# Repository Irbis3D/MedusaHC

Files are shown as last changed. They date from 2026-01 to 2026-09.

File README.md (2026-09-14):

# MedusaHC V0.2 (Beta)

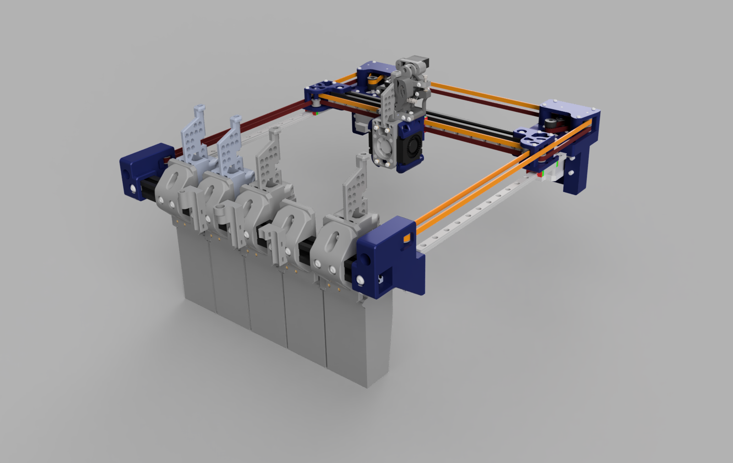
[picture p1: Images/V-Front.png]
MedusaHC V-Front


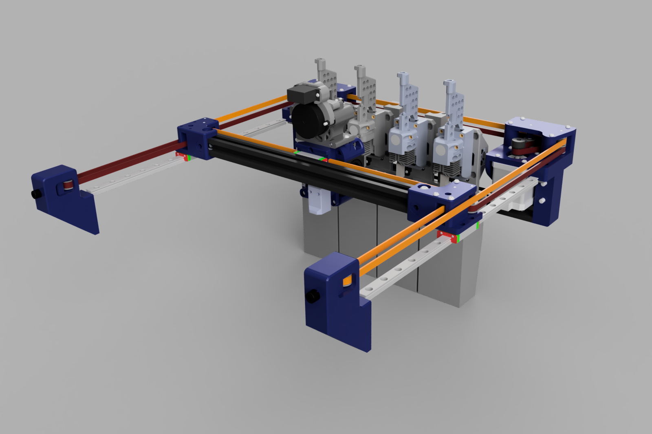
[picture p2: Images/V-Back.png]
MedusaHC V-Back


MedusaHC is an open-source toolchanger (hotend-changer) project.
This is a beta version of the project. It is not finished yet, and there may be bugs during operation. The project will be updated gradually.

> [!IMPORTANT]
> **[Installation, update, removal, and manual setup instructions](INSTALLATION.md)**
>
> **If, for any reason, you are still using the macro-based version, it is available in the [legacy-macros branch](https://github.com/Irbis3D/MedusaHC/tree/legacy-macros). However, I strongly recommend migrating to the new Python-based version while the transition is still straightforward.**

This project is licensed under GNU GPLv3.
You're free to use, modify, and share it — just keep the copyright/license notices intact, provide the source code, release derivatives under GPLv3 too, and note what you changed.

For the exact terms, see the LICENSE file.

## Support the project

If you have the ability and desire to support the project, you can do it in several ways:

https://irbis3d.xyz/

- Patreon — monthly support: https://patreon.com/Irbis3D
- Ko-fi / Buy Me a Coffee — one-time donations: https://buymeacoffee.com/Irbis3D
- YouTube Super Thanks — under any video: https://youtube.com/@Irbis3D

Your support helps me create more content, upgrade gear, and keep experimenting with cool ideas.

Also, by buying parts using my links, you help as well.

## Software options

> [!IMPORTANT]
> The `main` branch now uses the Python-based tool-change controller. It has
> completed extended testing on the development printer, has proven reliable,
> and is the strongly recommended implementation for new and existing
> installations. Current optional MedusaHC modules are developed against it.

The controller keeps the familiar MedusaHC commands and configuration
structure while moving pickup, parking, feeder, priming, cleaning, and sensor
verification into the Klipper Python module `medusahc.py`. This avoids the
chained execution and unnecessary fixed waits of the original macro controller.

The final working macro-based implementation is preserved in the frozen
[`legacy-macros`](https://github.com/Irbis3D/MedusaHC/tree/legacy-macros)
branch. It retains the old klipper-toolchanger calibration workflow and is
provided for compatibility and rollback, but new functionality is not planned
for that branch. Migration to the Python controller is strongly recommended.

The optional [MedusaHC Control](https://github.com/Irbis3D/MedusaHC-Control)
panel is installed independently. Its current transitional release supports
the Python controller and the preserved legacy macro names.

Optional features are kept in separate projects so they can be installed and
updated independently:

- [MedusaHC-Calibrate](https://github.com/Irbis3D/MedusaHC-Calibrate) — automatic
  tool-offset calibration using a contact sensor, native Eddy Tap, or Eddy Tap
  together with a stationary Eddy Coil and EddySeek;
- [MedusaHC-Mainsail](https://github.com/Irbis3D/MedusaHC-Mainsail) — experimental
  Mainsail integration for the MedusaHC Control panel.

The base MedusaHC configuration does not require either optional module.

## Credits

This project uses some work and ideas from the Dragonburner project by chirpy2605:
https://github.com/chirpy2605/voron/tree/main/V0/Dragon_Burner

As well as from Sherpa_mini-Extruder by Annex-Engineering
https://github.com/Annex-Engineering/Sherpa_Mini-Extruder

The alternative V-Front mounts with a profile opening were contributed by **GN500**. GN500 has also published an MGN12H version on Printables.

## Current status and compatibility

Right now, MedusaHC is an add-on for my Duender project:
https://www.printables.com/model/1798903-duender-project-ender-3-to-corexy-conversion
https://github.com/Irbis3D/Duender

V0.2 supports two basic dock layouts:

- **V-Front** — the hotend bases are installed in front of the print area. This layout can accommodate more tools and may be more convenient when adapting MedusaHC to other CoreXY printers, including Voron-style machines.
- **V-Back** — the hotend bases are installed behind the print area, closer to the XY motors. The shorter effective belt path between the drive and the dock area reduces the influence of belt elasticity during tool changes and can improve docking repeatability. It also keeps the front of the printer unobstructed and the print area easy to see.

The supplied STEP assembly is a visual and mechanical reference. It demonstrates that up to **5 tools** can fit in the V-Front layout and shows a **4-tool** V-Back arrangement. The supplied configuration and OrcaSlicer profile are intentionally set up for **4 tools**.

The project can potentially be adapted for other classic CoreXY printers and, with suitable mounting changes, for CoreXY machines with a flying gantry. Available space, axis travel, dock coordinates, parking positions, wiring, and controller capacity must be checked for every printer.

The point of the project is that, unlike classic toolchangers, MedusaHC swaps only the hotend as a tool (with heater, thermistor, and fan). I am not the first who did this and I will not be the last. This topic is actively discussed and developed on my
Discord server - https://discord.gg/ae44FHv786

## What is new in V0.2

- V-Front and V-Back dock layouts use the same Python tool-change controller.
- `variable_tools_direction` automatically reverses layout-dependent pickup, drop, cleaning, and priming movements.
- The supplied configuration uses four tools numbered normally from `T0` to `T3`.
- The base, nozzle-cleaning, PTFE-cleaning, priming, and wire-management parts have been updated.
- Native Klipper Eddy tap replaces Eddy-ng for Z probing.
- Automatic tool-offset calibration is available separately through
  MedusaHC-Calibrate and does not require klipper-toolchanger.
- Updated OrcaSlicer projects, a 4-tool printer preset, and post-processing scripts are included.
- Camera-assisted tool calibration is not currently supported. A new native or
  adapted camera module may be developed later.

See [CHANGELOG.md](CHANGELOG.md) for the complete V0.2 release notes.

## Documentation and audience

For a general understanding, I recommend watching the first video about this project on my YouTube channel. You will not find all the information there, but you can get a general idea of how it works.

MedusaHC video (https://www.youtube.com/watch?v=hpV5Z1TnGdY)

Recently a video about the hardware part of MedusaHC was released on the channel. In the next video I will explain the software side — configuration, macros, and how everything is set up.

MedusaHC Part 2 — Hardware Explained (https://www.youtube.com/watch?v=F2OpeA6CTm0)

But the main thing is that, thanks to the huge effort of **TallothEndill**, a detailed text manual is already in progress and largely covers the project. It is not fully finished yet, but it is already very useful as a reference:

[MedusaHC manual (work in progress)](https://drive.google.com/file/d/1KkSGdeQZzl4gnCMKlBloHfCNIlD4JwAP/view)

## Parts, BOM, and files

Link to BOM

https://docs.google.com/spreadsheets/d/1xkOzb10DBJzalW4n1tYroh-m_ZFsTQipC1BpUh5ZMWY/edit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

For this project you need to buy quite a lot of parts. I tried not to use expensive and rare components. You can find the list at the link above. This file will be updated as the project updates.

The full STEP file contains both V-Front and V-Back reference assemblies. It is primarily intended to show the construction, available space, and the relationship between the parts. It is not a promise that the example tool count matches the supplied 4-tool configuration. The file was created in Fusion 360; FreeCAD may have problems opening it because of STEP compatibility differences.

Printable STL files are organized by subsystem. The layout-specific mounting parts are separated into `V-Front Mounts` and `V-Back Mounts` folders. Common base, feeder, hotend, and toolhead parts are stored in their own folders.

The OrcaSlicer 3MF projects and the 4-tool printer preset are located in the `Slicer` folder. They show the printer configuration and a multicolor test project. Post-processing paths are computer-specific and must be configured by the user.

To understand how the system is assembled, use the STEP file together with the STL folder descriptions. I printed the functional parts in ABS with 98% infill.

### Duender XY mounting compatibility

The layout-specific mounts supplied in this V0.2 package are designed for a **Duender with MGN9H rails on the XY axes**.

An MGN12H installation requires the MedusaHC mounting system to be raised slightly to compensate for the different rail and carriage geometry. The required correction depends on the selected Duender parts and must be checked during assembly.

#### V-Front installation

There are two mounting options for a front installation:

1. Keep the standard Duender front XY mounts and glue the included `Base_Profile_Mount_L.stl` and `Base_Profile_Mount_R.stl` adapters to them. The adapters are located in `STLs/V-Front Mounts`.
2. Replace the standard front mounts with the V-Front mounts contributed by GN500. These mounts include an opening for the front profile. The MGN9H versions are included in this package; an MGN12H version is available from GN500 on Printables.

No other Duender kinematic changes are required for the V-Front installation. The X rail and belt path remain in their normal orientation.

#### V-Back installation

For a rear installation, the standard Duender front mounts remain installed. The MedusaHC docks are attached to the rear profile using the new V-Back mounting parts.

Because all tools are behind the X axis, the complete X axis must be turned toward the rear:

- install the new reversed left and right X-axis mounts;
- move the X linear rail to the opposite side of the profile;
- route the belts behind the X profile;
- check the complete belt path and all moving clearances before homing.

At the toolhead belt clamp, several belt teeth must currently be removed from the clamped section so the carriage can seat fully. A small drop of cyanoacrylate adhesive can be used to reduce the risk of belt slippage. This is a temporary assembly solution and may be redesigned later.

Depending on the printer geometry and the required rear clearance, the complete Z axis together with the bed may also need to be shifted forward.

## Important notes

All parts must be printed with good enough quality so that parts do not get stuck inside each other. Some contact surfaces may need a bit of sanding to make them smooth.

When installing magnets (I glued them, and all magnet holes have access from the back for removing magnets), be careful and do not mix up the polarity.

The M3 pins that act as hotend guide pins must be pressed into the plastic as straight as possible. I hammered them in, but it is better to do it carefully using a vise. The two lower M3 30mm pins are mandatory. The upper M3 20mm pins are optional, if the hotend does not hold firmly enough.

On the hotend, the matching holes for the pins must be prepared. Personally, I used M3 inserts for this, and I drilled them first with a 3mm bit (they are usually about 2.9mm), and then with a 3.2mm bit (my bits are closer to 3.1mm). Even though the size looks odd, these drill bits are quite common.

Before drilling the actual part, I recommend testing on some test piece to make sure the hole is not too large. The pins must slide in freely, but must not be loose.

Maybe later it will be possible to use brass bushings of the correct diameter, but they take more space and may not fit.

The pressure lever spring for the feeder from the standard Sherpa Mini kit does not fit. I just found a suitable spring in my spare parts. When a spring with known dimensions is selected, I will add this information to the BOM.

The spring for the feeder opener lever is just a regular spring from a ballpoint pen.

Other than that, you just need to assemble everything carefully so nothing is loose and nothing binds. As I said earlier, I will explain more nuances in the video.

## Electronics

For this project, I use the **BTT Manta M8P** board. For a 4-hotend configuration, it can be considered the most optimal option. It has enough ports for absolutely everything, including 4 hotend heaters and even a dedicated Servo port (which is sufficient without a DC-DC converter). My configuration files are set up specifically for this board with a **CB2** module.
https://s.click.aliexpress.com/e/_oktZaKt

Roughly the same capabilities are provided by boards like **BTT Octopus Pro**, **Kraken**, and other “large” boards, with the main difference being that the HOST is located separately.
https://s.click.aliexpress.com/e/_c2wuASWJ
https://s.click.aliexpress.com/e/_c3kPDyx1

When using other boards, it is possible to connect additional boards to a single host.

### Ports required per hotend (on the controller board)

For each hotend, the board must have the following ports:

- heater port (MOSFET-controlled; can be used either hotend heaters or the bed)
- thermistor port
- fan port (either PWM-controlled or a constant 24V port)
- endstop port for the endstop located on the base of that hotend

### Ports required for the toolhead

- one extruder motor port
- part cooling fan port(s)
- toolhead endstop port
- port for the auto-calibration sensor (I use **BTT Eddy** connected via CAN)
- servo port — if the board does not have a dedicated servo port capable of supplying stable 5V under load, it is recommended to power the servo via a **24V→5V DC-DC converter** from the main power supply

### Power considerations

Additional hotends require additional power from the PSU.

From experience, a standard **350W** power supply is reliably sufficient for **2 hotends**.
For **3 hotends**, it can be enough with a high-quality PSU.
For **4 hotends**, it is definitely not enough.

In my setup with the **Manta M8P**, I use one **350W** power supply for the heated bed, and another **350W** power supply for everything else.

## Configuration setup

The main printer parameters, as before, are located in the `printer.cfg` file.
In general, the configuration is no different from a standard Duender config.

The exception is that the extruder configuration block has been moved into the MedusaHC configuration file. More on this below.

### Additional modules

Personally, I use **klipper-tmc-autotune** for tuning motor drivers.
(This is optional.)

### Display and sensors

In my opinion, the optimal screen is **BTT HDMI5**.

https://s.click.aliexpress.com/e/_c4odBUeJ

I use **BTT Eddy** connected through CAN. V0.2 no longer uses Eddy-ng or a modified `probe_eddy_ng.py` file. Eddy tap probing is handled by current Klipper functionality.

Native Eddy Tap can be used by the optional MedusaHC-Calibrate module to
measure the Z relationship between tools. Full X/Y/Z calibration can use a
SexBall-style contact sensor or combine Eddy Tap for Z with a stationary Eddy
Coil and EddySeek for XY.

## Arcs support

The `[gcode_arcs]` block and the **Arc fitting** setting in the slicer allow the slicer to use **G2** and **G3** commands to print arcs instead of short straight segments.

On weak HOST systems, problems were observed with this feature. In such cases, it should either be disabled or the resolution should be set higher than **0.1**.

## System configuration files modified for this setup

### sensorless.cfg

This file has been modified quite heavily to make sensorless homing safer and to improve repeatability without physical XY endstops.

The safe parking and homing side depends on the dock layout:

- with **V-Front**, park away from the docks, toward the rear of the printer;
- with **V-Back**, park away from the docks, toward the front of the printer.

The exact coordinates depend on the printer. Check the homing sequence and every parking move before testing at normal speed. Parking positions used by `END_PRINT`, `PAUSE`, `RESUME`, `CANCEL_PRINT`, calibration macros, and service macros must also be adjusted for the selected layout.

The supplied Duender 4-tool configuration uses front docks and rear parking.

### Line_Purge_examples.cfg

Modified so that the purge line is printed not along the X axis, but on the left side of the bed along the Y axis.

In my setup, **Adaptive** is disabled, so the line is always printed in the same place. It can be enabled if desired, in which case the line will be printed closer to the model.
(Optional.)

### klipperScreen.conf

KlipperScreen support is optional. A custom menu can be created for the main MedusaHC macros, but `KlipperScreen.conf` is not included in this V0.2 folder.

### Camera calibration

Camera-assisted tool calibration is not currently supported. The previous
experimental example was not compatible with the current configuration and
has been removed. A new native implementation or an integration with another
project may be added later.

### macros_examples.cfg

The `START_PRINT`, `END_PRINT`, `PAUSE`, and `RESUME` macros were heavily modified.

The start macro receives from the slicer the required temperatures for the hotends that will be used during the print and heats them up. At the moment, it does not take into account whether a hotend will be used soon or should wait its turn. I am not happy with this behavior yet, but I have not found a good solution so far.

The pause and resume macros are also heavily adapted for this system. The idea is that during tool changes, the printer remembers which tool it is trying to pick up. In case of a failure, the printer pauses and gives time to fix the issue.

It is enough to manually adjust the hotends so that they are in one of the “correct states” and then press resume. Regardless of what was done manually, the printer will automatically check which hotend it planned to take before the pause, park the X and Y axes (this is necessary if the motors skipped steps), and then ensure that the print continues with the correct hotend.

This procedure still has some shortcomings. A visible defect may remain on the model at that spot. Additionally, when parking with sensorless homing, the zero point may shift slightly, which can appear on the model as a small layer shift. In most cases, this shift is very small.

---

## MedusaHC configuration

### Semi-manual Core installation

The Core installer copies the Python controller and `pin_watch.py`, then creates
a separate editable example configuration under
`~/printer_data/config/MedusaHC/`. It does not edit `printer.cfg`, restart
Klipper, or overwrite an existing configuration directory.

```bash
bash -c "$(curl -fsSL https://raw.githubusercontent.com/Irbis3D/MedusaHC/main/install-online.sh)"
```

The supplied example targets a four-tool V-Front Duender with a BTT Manta M8P
V2.0. Its `MHC_config.cfg` contains a complete `[extruder]` definition, so
review and remove conflicting sections from the existing printer configuration
before manually adding:

```ini
[include MedusaHC/MHC_config.cfg]
```

See **[INSTALLATION.md](INSTALLATION.md)** for update, status, safe removal,
complete removal, path overrides, exact installer behavior, and manual
installation instructions. Core configuration migration and automatic printer
setup are intentionally not implemented yet.

The main files responsible for MedusaHC operation are:

- `MHC_config` — configuration of all hardware related to MHC
- `MHC_variables` — variables for configuring various coordinates, speeds, and similar parameters
- `MHC_macros` — the main file containing all macros responsible for MHC functionality

And the `pin_watch.py` script — in the current version, a dedicated script is used to monitor sensor states. It listens to the sensors in real time and updates variable states accordingly. Based on this data, MHC determines what is installed where and checks for errors.

The file must be uploaded via FTP to the folder:

```

/home/biqu/klipper/klippy/extras

```

(` /home/pi/klipper/klippy/extras ` for Raspberry Pi users)

The script was integrated recently and has not been tested on different systems yet. If problems appear, I will make an additional version that works purely on macros, with manual state updates via a macro. (Feedback is required.)

All (or at least almost all) macros are designed to be universal and work with any number of hotends. The number of hotends is defined in the configuration and variables. My current config is for **4 hotends** (higher counts have not been tested yet).

## MHC setup

### MHC_config file

#### [pin_watch io] block

This block configures the `pin_watch` script.

- `sync_toolchanger: 0` — optional compatibility synchronization with
  klipper-toolchanger. It is disabled by default and is not required by
  MedusaHC or MedusaHC-Calibrate. Enable it only after installing and minimally
  configuring klipper-toolchanger separately.
- `sync_mainsail_tools: 1` — highlights the active tool button in the Mainsail/Fluidd tools panel. When a tool is successfully picked up, the corresponding `T<N>` button gets `variable_active = 1`, others get `0`.
- `sync_mainsail_sensors: 1` — turns each tool's button into a state indicator lamp via `variable_color`. The active tool is shown in blue, parked tools (endstop pressed) in green, missing tools (endstop released) in red. The lamp is updated immediately from pin edges, so anomalies are visible in real time.
- `color_active`, `color_pressed`, `color_released` — hex colors (without `#`) used by the indicator lamp. Defaults: blue / green / red.
- `verbose` — enables additional console output with detailed pin state information.
- `pin_e` — microswitch pin located on the toolhead.
- `pin_t0`, `pin_t1`, etc. — microswitch pins on the bases of the corresponding hotends.

Each sync feature is independent. Enable only the integrations you actually
use.

#### [duplicate_pin_override]

Since a single extruder motor is used for all tools, this block must specify the **step**, **dir**, and **enable** pins for that motor. This allows all extruders to use the same pins without causing configuration errors.

#### [extruder], [extruder1], etc.

Nothing special here. All extruders share the same **step**, **dir**, and **enable** pins. The rest is standard extruder configuration.
A corresponding `extruder` block must be created for each hotend.

#### [gcode_macro T0], [gcode_macro T1], etc.

Mandatory macros that “create” additional tools in the system.
The number of these macros must match the number of hotends.

Each `T<N>` macro must declare two variables: `variable_active: 0` and `variable_color: ""`.
These are required by Mainsail/Fluidd to render the tools panel and to receive runtime updates from `pin_watch` when `sync_mainsail_tools` or `sync_mainsail_sensors` is enabled.

#### [servo my_servo]

The last mandatory block. This defines the servo used to help open the feeder.

After that come optional parameters:

- fan configuration (if you are using controllable fan ports)
- additional heater parameters

It is recommended to change heater-related parameters only if there are heating problems, and only as a last resort, preferably temporarily.

---

### MHC_variables file

#### [save_variables]

This block defines the file where tool offsets are stored so they can be restored after a restart.
(It is required when using auto-calibration.)

#### [gcode_macro _TOOL_CFG]

This macro contains the main coordinates and distances used in the system, as well as the speeds and accelerations for the tool change procedure.

- `variable_tools_direction` — selects the dock orientation:
  - `1` for **V-Front**;
  - `-1` for **V-Back**.

  This value automatically reverses the required pickup, drop, cleaning, and priming movements. Do not manually invert the individual movements in `MHC_macros.cfg`.

- `variable_x_t0`, `variable_x_t1`, etc. — the **X coordinate** where each hotend is mounted on its base.
  Enter the real printer coordinates and keep the tools numbered normally from `T0` upward. The supplied Duender configuration uses **65 mm** spacing. The minimum safe spacing depends on the printed parts, hotends, wiring, and available travel.

- `variable_y_safe` — the **Y coordinate** where the extruder with an inserted hotend can freely move left and right without hitting other hotends on their bases.
  For V-Front this is normally in front of the bed; for V-Back it is behind the bed. Depending on the frame and profile lengths, the dock area may reduce usable Y travel.

- `variable_y_latch` — the **Y coordinate** where the toolhead fully engages with the hotend.
  This must be set very precisely so that the toolhead presses firmly against the hotend, but without causing the motors to skip steps.

- `variable_x_shift` — the distance the hotend needs to move along the X axis from `variable_x_t` in order to remove it from the base keyhole.

- `variable_fast_accel`
- `variable_fast_speed` — speeds and accelerations for tool changes. During the change process, there are slowdowns that are calculated as proportions of these parameters.

- `variable_y_prime` — the **Y coordinate** where it is safe to prime filament into the bin.
- `variable_y_brush` — the **Y coordinate** of the approximate center of the nozzle cleaning brush.
- `variable_x_prime_shift` — the **X distance** from `variable_x_t` to the priming point.

The user only needs to select `variable_tools_direction` and enter the correct coordinates. The MedusaHC macros derive the movement direction from that setting. Parking coordinates outside the MedusaHC tool-change macros are printer-specific and must still be checked separately.

- `variable_e_open`
- `variable_e_close` — the distance and direction (in mm of filament) the extruder motor rotates to open and close the feeder latch.
  Sign sets direction: by default open is negative, close is positive. Flip the sign if your extruder is wired or mounted the other way around.

- `variable_e_cur_high_mult` — multiplier applied to the extruder's base TMC `run_current` to get the boosted current used during feeder **OPEN**.
  The boost is needed so the motor has enough torque to break the mechanical lock without skipping steps. Typical range: **1.3 – 1.8**.
  Base and boosted currents are cached at initialization. Save changes to the
  multiplier or `run_current` in the configuration and restart Klipper while idle.

#### [gcode_macro _GLOBAL_STATE]

- `variable_max_tool: 4` — required by the macros to operate with the specified number of hotends.

After this, there are parameters that are used internally by the macros.
They should **not** be changed.

#### [gcode_macro _TOOL_STATE_0], [gcode_macro _TOOL_STATE_1] and so on

Each hotend must have its own `TOOL_STATE` macro (`_TOOL_STATE_0`, `_TOOL_STATE_1`, and so on), where all parameters for that specific hotend are defined.

- `variable_prime_amount` — the amount of filament (in mm) extruded during priming.
  A small value (**7–8 mm**) is suitable when printing with a draft/wipe tower.
  A larger value (**14–16 mm**) can be used for printing without a tower.

- `variable_prime_speed` — priming speed.

- `variable_prime_retract`, `variable_prime_retract_speed` — length and speed of the retract after priming.

- `variable_clean_move` — `1` to perform the complete PTFE and brush-cleaning sequence after priming; `0` to skip all cleaning movements and move directly to `y_safe`.

- `variable_x_clean_move`

- `variable_y_clean_move`

- `variable_clean_move_speed` — brush crossing speed in mm/s for this tool, used both by CLEAN and by cleaning after pickup. Read from `_TOOL_STATE_n` on each operation; changes apply to the next cleaning cycle.

Pickup moves to `y_prime` at the X position set by `x_prime_shift` before
extrusion. All priming and the prime retract finish there. The next move is
to `y_brush`, before any cleaning X stroke. The entire slow/fast PTFE path
then runs relative to `y_brush`; the crossing starts 2 mm toward the dock from this
reference, preserving the original mirrored geometry. Both Y values default
to -45 mm. The PTFE passes retain `ptfe_clean_slow_speed`.

- `variable_clean_retract`

- `variable_clean_retract_speed` — additional retract after cleaning.

- `variable_first_prime_enabled` — `1` to enable first-use priming for this tool, `0` to disable it.

- `variable_first_prime_flag: 1` — internal runtime state managed by the macros. Do not change it manually.

- `variable_first_prime_amount` — the amount of filament (in mm) extruded during the first use of the hotend in a print.
  This value is usually larger than the regular priming amount.

- `variable_first_prime_speed` — speed of the first-use priming.

## Notes

Keep in mind that the lengths of these two retracts are linked to the slicer parameter **“Retraction when switching material”**.
If the priming retract and the cleaning retract are **1 mm** each, then **“Retraction when switching material”** must be set to **2 mm**.

In some situations, with certain filaments and when printing without a draft tower, these parameters require additional calibration.

## Main macros file

And finally, the most important file. Nothing needs to be configured here (hopefully it will stay that way).
I will not describe the system operation in full detail here. I will explain it a bit more in the video.
Below is a short overview, just to understand the main algorithms.

---

### Python initialization

The Python controller initializes after Klipper becomes ready; there is no
`INIT_SENSOR_STATE` macro on `main`.
It is responsible for:

- assigning variables that depend on printer parameters
- initial tool assignment
- applying tool offset values from the `saved_vars` file to the variables in `[gcode_macro _TOOL_OFFSET]`

---

### Feeder control macros: OPEN, CLOSE and sub-macros

These macros control the feeder.

The Python controller ignores OPEN when its stored feeder state is already open.

There are no dedicated sensors to track the feeder state, so the state is stored in a variable. The printer uses this variable to determine whether the feeder is open or closed.

Since closing the feeder is relatively safe, it is forced on printer startup. From that moment on, the printer knows the feeder state and will not try to open it incorrectly.

The old macro controller documented an OPEN/CLOSE workaround after motor
disable. That is not part of the current slicer start sequence, which calls
CLOSE. The Python controller tracks feeder state internally.

---

### Python tool-change controller

The physical pickup, drop, feeder, cleaning, priming, offset, and verification
logic is implemented by `klippy/extras/medusahc.py`. The short public macros retain
the familiar Mainsail and slicer interface without exposing internal helper
commands.

The **main command responsible for tool changes is `SET`**. It is also called
by the `T` macros.

When `SET` is called with a tool parameter (`SET T=0`, `SET T=1`, etc.), the printer checks what is currently installed, based on data from the `pin_watch` script object.

- If no hotend is installed, the printer will pick up the requested hotend.
- If a different hotend is installed, the printer will first drop it, then pick up the requested one.
- If the requested hotend is already installed, the printer will simply apply the offsets for the selected tool and finish.

All of this happens automatically, without the need to manually specify anything.

Thanks to the `pin_watch` script, the printer always knows its state, even if you manually remove or install hotends.

---

### Dropping a tool and error handling

Use the public `DROP_TOOL` command to park the currently installed hotend.
The included `_DROP` macro calls `MHC_DROP` for internal users such as
MedusaHC-Calibrate; it does not add a Mainsail button.

---

All pickup and drop macros include checks.

If after dropping or picking up a hotend the script detects that the sensor state does not match the expected one (for example, the drop failed, pickup failed, or some other hotend fell off its base), the printer will pause and enter an error state.

After fixing the problem and resuming, the printer will pick up the planned tool and continue printing.

The current Python controller distinguishes an undetermined live sensor state
from a failed SET/DROP operation. Interfaces can use `medusahc.sensor_error`
and `medusahc.last_error`; see the [sensor status guide](docs/sensor-status.md).
Recovery after a failed change, and manual PAUSE/RESUME behavior, require the
active printer macros to call `MHC_RESUME`. See the
[PAUSE/RESUME migration guide](docs/recovery.md) before updating a printer.

The frozen macro implementation and its original chained helper macros remain
available in the `legacy-macros` branch.

---

## Orca Slicer configuration

All slicer settings can be viewed by opening `Slicer/4rcaCube_orca_project.3mf` as a project. A separate 4-tool printer preset is provided in `Slicer/Printer presets.zip`.

All MHC-specific parameters are located in the printer settings.

### Machine G-code tab

The following sections are modified:

- Start G-code

```gcode
CLEAR_PAUSE
_PRIME_FLAGS_SET
M104 T0 S150
M190 S[bed_temperature_initial_layer_single]
G28
Z_TILT_ADJUST
CLOSE
START_PRINT INITIAL_TOOL=[initial_tool] INITIAL_TEMP={first_layer_temperature[initial_tool]} EXTRUDER_TEMP={is_extruder_used[0] ? idle_temperature[0] : 0} EXTRUDER1_TEMP={is_extruder_used[1] ? idle_temperature[1] : 0} EXTRUDER2_TEMP={is_extruder_used[2] ? idle_temperature[2] : 0} EXTRUDER3_TEMP={is_extruder_used[3] ? idle_temperature[3] : 0} BED_TEMP=[bed_temperature_initial_layer_single]
PRIME_FLAGS_CLEAR
T{current_extruder}
CLEAN
LINE_PURGE
G92 E0
```

- End G-code

```gcode
END_PRINT
```

- Change filament G-code

```gcode
T{next_extruder}
```

- The **Layer change G-code** also includes a modification that assigns a layer variable. It is not used at the moment, but may be useful in the future.
```gcode
;AFTER_LAYER_CHANGE
_LAYER_SET L={layer_num}
;[layer_z]
```

### Multimaterial tab

You must specify the number of extruders. After that, separate tabs with settings for each hotend will appear.

All print parameters related to multimaterial printing are also located in the **Multimaterial** tab.

---

## G-code post-processing script

In addition, to optimize the workflow, I use a G-code post-processing script called `SET_FINISH.py`.

This script slightly changes the order of movements when transitioning back to printing after a tool change.
It also replaces some temperature commands that include waiting with non-waiting commands.

This is done so that, when **Ooze prevention** is enabled, the printer does not wait for temperature stabilization after every tool change.

Be careful with **Ooze prevention** settings. The heating time must always be sufficient for the hotend to reach the target temperature.

To use this script, **Python must be installed on the computer**.
You must specify the path to Python and to the script itself in the **Others** tab, in the **Post-processing Scripts** section.

The path stored in a 3MF project is computer-specific. Replace both paths with the actual Python executable and the copy of the script on your computer. A typical command has this form:

```

"C:\path\to\python.exe" "C:\path\to\SET_FINISH.py" 12

```

`SET_FINISH_Snapmaker_Orca.py` is also included for the alternative workflow used with Snapmaker Orca. See the `Scripts` folder README before selecting a post-processing script.

## Tool offset calibration

Offsets work relative to the first tool.
That means all offsets for **T0** are equal to `0`, and all other tools are calculated relative to **T0**.

Keep in mind that this system uses **G-code offsets**.
That is, how much the entire coordinate system needs to be shifted so that the hotend ends up in the same position as **T0**.

Do not confuse this with *tool offset*, where the value indicates how much the hotend itself is shifted from the desired point.

As a result, **tool offset has the opposite sign of the G-code offset**.

---

### Manual tool offset calibration

Saved offsets override the initial `_TOOL_OFFSET` values in `MHC_variables.cfg`
at startup. Do not disable initialization for manual calibration. Save your
measured G-code offsets with `SAVE_VARIABLE`, using keys such as
`t1_gcode_x_offset`, `t1_gcode_y_offset`, and `t1_gcode_z_offset`.
For example: `SAVE_VARIABLE VARIABLE=t1_gcode_x_offset VALUE=0.12`.
Restart Klipper while idle to load these values into `_TOOL_OFFSET`.

---

### Z offset calibration

Z calibration is done manually, via the web interface or the printer menu.

Lower each hotend to the bed and calculate the offset relative to the first hotend.

---

### XY offset calibration

For this, you need to print special calibration models.
I used this one:

https://www.printables.com/model/129617-offset-xy-dual-extruder-idex-calibration

Place **one fewer copy** of this model than the number of hotends on the bed.

- The bottom part of all copies is printed with **T0**
- The top parts are printed with different hotends: **T1, T2**, and so on

Keep in mind that this test shows **tool offset**, so for MHC you need to **invert the sign** of the obtained values.

Save the resulting offsets as described above. The corresponding variables
in `_TOOL_OFFSET` are startup defaults only when no saved value exists.

---

## Optional automatic tool-offset calibration

Automatic calibration is maintained as the independent
[MedusaHC-Calibrate](https://github.com/Irbis3D/MedusaHC-Calibrate) module. It is
not required for normal MedusaHC operation and can be installed, updated, or
removed without replacing the base MedusaHC configuration.

The module provides three calibration methods:

- full X/Y/Z calibration with a SexBall-style contact sensor;
- Z-only calibration with native Klipper Eddy Tap;
- full X/Y/Z calibration using native Eddy Tap for Z and a stationary BTT Eddy
  Coil with [EddySeek](https://github.com/charliemayall/EddySeek) for XY.

All methods use T0 as the reference, store the resulting G-code offsets in
`saved_vars.cfg`, and apply them through the existing MedusaHC offset macros.
Installation, sensor coordinates, safe travel limits, contact directions,
EddySeek setup, and validation procedures are documented in the calibration
module repository.

The legacy `klipper-toolchanger`-based calibration files are no longer bundled.
`pin_watch.py` still contains optional compatibility synchronization for users
who already use klipper-toolchanger, but that integration is disabled by
default and is unrelated to MedusaHC-Calibrate.

### Optional klipper-toolchanger compatibility

Users who need another plugin that depends on klipper-toolchanger may install
it separately and create a minimal configuration like this:

```ini
[toolchanger]
initialize_on: manual
verify_tool_pickup: False
require_tool_present: False
on_axis_not_homed: abort

pickup_gcode:
    T{tool.tool_number}

[tool T0]
tool_number: 0

[tool T1]
tool_number: 1
```

Add one `[tool Tn]` section for every configured MedusaHC tool, then set
`sync_toolchanger: 1` in `[pin_watch io]`. MedusaHC continues to perform the
physical tool changes; this option only mirrors the detected active tool into
klipper-toolchanger. Keep it disabled when no other installed component needs
that state.

---

## Final notes

This project is fully open source. You are free to use it, modify it, and build your own derivatives.

If you find the project useful, any kind of support helps — it allows me to spend more time on development, testing, and experiments. The project will be updated gradually, as new ideas appear and as I have the time and resources to work on it.

Most discussions about this project and similar toolchanger concepts take place on my
Discord server:

https://discord.gg/ae44FHv786

That is where new ideas are tested, problems are discussed, and future directions are shaped.

## License

This project is licensed under the GNU General Public License v3.0.
See the LICENSE file for details.

## Author

MedusaHC is an open-source project developed by Sergei Irbenek (Irbis3D).

Attribution is not required by the license, but is highly appreciated.

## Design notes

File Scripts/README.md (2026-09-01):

# Scripts

This folder contains optional post-processing scripts for the slicer workflow.
The Klipper modules are stored separately in `klippy/extras/`, matching their
installation destination.

## `SET_FINISH.py`

OrcaSlicer post-processing script. It adjusts the first travel moves after a tool change and converts temperature-wait commands after the first layer where required by this workflow.

## `SET_FINISH_Snapmaker_Orca.py`

Alternative post-processing script used for the Snapmaker Orca workflow. It adjusts the post-tool-change travel order without the additional temperature-command conversion performed by `SET_FINISH.py`.

Python must be installed on the slicing computer. Configure the local Python and script paths in OrcaSlicer; paths saved on another computer will not work.

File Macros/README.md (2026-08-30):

# Configuration files

This folder contains the Klipper configuration example and the macros used by MedusaHC V0.2.

The supplied configuration is a **4-tool V-Front Duender example**. It is not a universal drop-in printer configuration. Before use, check all MCU identifiers, pins, axis limits, homing directions, TMC settings, PID values, probe offsets, dock coordinates, and parking positions.

The main MedusaHC files are:

- `MHC_config.cfg` — tool sensors, shared extruder hardware, heaters, fans, servo, and tool commands.
- `MHC_variables.cfg` — tool count, layout orientation, dock coordinates, cleaning/priming settings, and stored offsets.
- `MHC_macros.cfg` — the public macro interface and small compatibility wrappers for the Python controller.
- `medusahc.py` from the `Scripts` folder — pickup, drop, feeder, cleaning, priming, error handling, and offset logic.
- `pin_watch.py` from the `Scripts` folder — real-time tool sensor monitoring.

## Layout selection

Set `variable_tools_direction` in `MHC_variables.cfg`:

- `1` — V-Front;
- `-1` — V-Back.

Then enter the actual X/Y coordinates for the installed docks. Pickup, drop, cleaning, and priming directions are derived automatically from `variable_tools_direction`. Parking coordinates in printer-level macros must still be adjusted separately.

## Probe selection

The example enables native Klipper Eddy support through `eddy_config.cfg`.

`bltouch.cfg` is an alternative backup configuration. Do not enable Eddy and BLTouch probe sections at the same time without resolving duplicate sections and pins. A BLTouch setup also requires manual review of `START_PRINT`, including the Eddy-specific `TAP_BASE_TOOL` call.

Tool-offset auto-calibration is intentionally not bundled into this base
configuration. Install the optional MedusaHC-Calibrate module when automatic
SexBall/contact, Eddy Tap Z, or Eddy Tap + EddySeek XYZ calibration is needed.

## External components

Some active sections depend on software installed separately:

- `pin_watch.py`, which must be copied to the Klipper `klippy/extras` directory;
- `medusahc.py`, which must be copied to the same Klipper `klippy/extras` directory;
- optional klipper-tmc-autotune;
- standard installation-specific files such as `mainsail.cfg` and `timelapse.cfg`.

`pin_watch.py` retains optional, disabled-by-default compatibility
synchronization with `klipper-toolchanger`. MedusaHC does not install or
require that plugin. A minimal optional configuration is documented in the
main project README.

Camera-assisted tool calibration is not currently included. A new native or
adapted implementation may be added later.

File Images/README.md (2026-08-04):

# Images

This folder contains reference renders of the V-Front and V-Back MedusaHC V0.2 layouts.

The renders illustrate the general arrangement only. Use the STEP assembly and the layout-specific STL documentation to verify mounting geometry and clearances.

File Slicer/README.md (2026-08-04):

# Slicer files

This folder contains OrcaSlicer examples for the supplied **4-tool** MedusaHC configuration.

- `Printer presets.zip` — 4-tool Duender/MedusaHC printer preset.
- `4rcaCube.3mf` — Generic 3mf 4-tool test project.
- `4rcaCube_orca_project.3mf` — OrcaSlicer project version of the test.

Open a 3MF as a **project** to inspect its printer, filament, and process settings.

Before printing:

- verify the bed size, printable height, tool count, start/end G-code, and all printer limits;
- configure the post-processing script path for the current computer;
- verify that the start G-code contains temperature parameters only for the configured tools;
- check that the selected parking positions are safe for V-Front or V-Back;
- confirm that the slicer tool order matches the physical `T0`, `T1`, `T2`, and `T3` assignments.

These files are examples and must be adapted to the actual printer, firmware, filament, and hotends.

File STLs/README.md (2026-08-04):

# Printable parts

This folder contains the printable MedusaHC V0.2 parts, organized by subsystem.

The supplied layout-specific mounts are currently designed for a **Duender with MGN9H rails on the XY axes**. An MGN12H installation requires the system to be raised slightly and the mounting geometry to be checked. Do not treat the MGN9H mounts as direct MGN12H replacements.

- `Base` — dock bases, bins, cleaning/priming parts, and cable/PTFE holders.
- `Feeder` — hotend-side feeder and servo-opening mechanism.
- `Hotend` — alternative printable hotend bodies.
- `Toolhead` — moving toolhead, extruder body, and MGN9H carriage mounts.
- `SexBall Mount` — printable parts for a SexBall-style contact calibration sensor.
- `V-Front Mounts` — layout-specific mounts for docks installed in front of the print area.
- `V-Back Mounts` — layout-specific mounts for docks installed behind the print area.

The V-Front and V-Back layouts share the common Base, Feeder, Hotend, and Toolhead parts. Select the layout-specific base and mounting parts required by the chosen arrangement.

The SexBall mounting parts are retained from the previous public release. Verify their compatibility with the selected contact sensor and printer geometry before printing.

Use the full STEP assembly as a visual reference. Verify quantities, orientation, clearances, hardware, and support requirements before printing a complete set.

For V-Front, the standard Duender front mounts can be retained by using the adapters from the Duender repository, or replaced with the included GN500 V-Front mounts. For V-Back, read the dedicated folder README before printing: the X axis, rail side, and belt path must be reversed.

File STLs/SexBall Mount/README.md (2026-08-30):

# SexBall Mount

This folder contains printable mounting parts for a SexBall-style contact calibration sensor.

The optional MedusaHC-Calibrate module can use a SexBall-style contact sensor
for full X/Y/Z tool-offset calibration without requiring a generic toolchanger
plugin. Verify the sensor design, mounting position, wiring, travel, and
printer clearances before use.

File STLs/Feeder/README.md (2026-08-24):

# Feeder parts

This folder contains the printable parts for the hotend-side feeder and its servo-assisted opening mechanism.

## Lever-driven opener update

The servo opener now uses two linked levers with two 693-2RS bearings at the joints instead of an eccentric cam. Removing this sliding contact makes the mechanism move more freely and gives it a more positive, repeatable opening action. The revised servo position also keeps it from protruding above the feeder, reducing its influence on system resonances.

Use the small servo horn supplied with the servo—the one with the short rounded arm and mounting holes. Cut away the rest of the horn, glue the remaining section into the printed lever, and optionally secure it with the original servo screw.

The new linkage makes the servo rotate in the opposite direction. Reconfigure and verify the open and closed servo angles before operating the feeder. Move the mechanism slowly during initial setup and make sure it reaches both positions without binding or over-travel.

Some parts received major mechanical changes, while others only gained minor improvements such as rounded edges. Reprinting the complete feeder set is recommended: there are relatively few parts, and the feeder must be disassembled for the upgrade anyway.

The mechanism must move freely without excessive play. Print quality, bearing and pin alignment, spring selection, and surface finishing directly affect reliable opening and closing. Refer to [`MedusaHC_Feeder_Lever_MOD.step`](../../STEP/MedusaHC_Feeder_Lever_MOD.step) to confirm orientation and hardware placement. This separate assembly documents the experimental feeder; it has not yet been incorporated into the main MedusaHC STEP assembly.

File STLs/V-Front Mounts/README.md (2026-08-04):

# V-Front mounts

These left and right **MGN9H** mounts are used when the MedusaHC docks are installed in front of the print area. The design with an opening for the front profile was contributed by **GN500**.

V-Front provides room for more tools and can be convenient when adapting MedusaHC to other CoreXY layouts. The supplied STEP reference demonstrates that five tools can fit, while the supplied configuration and slicer preset use four tools.

There are two supported approaches for a Duender front installation:

- keep the standard Duender front mounts and glue the included `Base_Profile_Mount_L.stl` and `Base_Profile_Mount_R.stl` adapters to them;
- replace the standard mounts with the GN500 V-Front mounts in this folder.

GN500 has also published an MGN12H version on Printables. The files in this folder are the MGN9H version. For V-Front, the X rail and belt routing remain in the standard Duender orientation; no other kinematic changes are required.

Set `variable_tools_direction: 1`, enter the real dock coordinates, and place printer parking positions safely away from the front docks.

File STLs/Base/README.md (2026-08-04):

# Base parts

This folder contains the stationary hotend dock components and the related cleaning, priming, PTFE, and wire-management parts.

- `Base_Bin_Main V-Front.stl` and `Base_Bin_Main V-Back.stl` are layout-specific variants.
- `Base_Mount_Main.stl` and `Base_Mount_Plate.stl` are common mounting components.
- `Nozzle_Close_Clean_Main.stl`, `PTFE Cleaner.stl`, and `Side PTFE Holder.stl` belong to the cleaning and filament-guiding system.
- The wire-holder files provide alternatives for the listed fitting combinations.

Use the STEP assembly to confirm the selected variant, orientation, and required quantity for the chosen number of tools.

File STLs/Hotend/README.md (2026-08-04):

# Hotend parts

This folder contains alternative hotend body variants:

- `Hotend_Main Bambu.stl` — Bambu-style hotend variant.
- `Hotend_Main TZ.stl` — TZ hotend variant.

Select the variant that matches the installed hotend. Verify heater, thermistor, fan, nozzle, wiring, and mechanical clearances before assembly.

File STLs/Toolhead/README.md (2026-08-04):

# Toolhead parts

This folder contains the moving MedusaHC toolhead components.

- `Extruder Main.stl` — main moving extruder/toolhead body.
- `MGN9H Mount Main.stl` — standard MGN9H carriage mount.
- `MGN9H Mount EDDY ADXL.stl` — MGN9H mount variant for the Eddy/ADXL arrangement shown in the project.

Choose the carriage mount that matches the installed sensors and verify probe offsets and cable clearances after assembly.

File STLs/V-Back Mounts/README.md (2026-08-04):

# V-Back Mounts

These **MGN9H** parts are used when the MedusaHC docks are installed behind the print area.

The folder contains left/right MGN9H axis mounts and alternative MedusaHC rear mounts for M3 or M5 hardware. Select only the mounting option that matches the frame and hardware.

V-Back places the docks closer to the XY motors, reducing the influence of belt elasticity during docking and improving repeatability. It also keeps the front of the printer unobstructed.

The standard Duender front mounts remain installed. The MedusaHC docks are attached to the rear frame profile with the new rear mounting parts in this folder.

The complete X axis must be reversed for this layout:

- use the new reversed X-axis mounts;
- move the X rail to the opposite side of the profile;
- route the belts behind the X profile.

Several belt teeth currently need to be removed where the belt is clamped by the toolhead mount. Otherwise, the carriage may not seat fully. A small drop of cyanoacrylate adhesive can be added at the clamped section to reduce the risk of slipping. This is a temporary solution and may be improved in a later revision.

Check rear clearance carefully. It may be necessary to move the complete Z axis and bed assembly forward.

Set `variable_tools_direction: -1`, enter the real dock coordinates, and move printer parking positions safely away from the rear docks.

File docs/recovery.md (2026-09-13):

# PAUSE/RESUME migration for the Python controller

This release changes recovery after a failed tool change. Updating Core copies
the new `klippy/extras/medusahc.py`, but **does not edit your active Klipper
macros or restart Klipper**. Before using the new recovery path, update the
`PAUSE` and `RESUME` sections that your printer actually includes. Keep your
own parking coordinates, messages and other printer-specific actions.

## What to change in your macros

1. Back up your active `PAUSE` and `RESUME` sections. Confirm they use
   `rename_existing: BASE_PAUSE` and `rename_existing: BASE_RESUME`, respectively.
2. In `PAUSE`, first check `printer.pause_resume.is_paused`. If it is already
   true, return without moving, calling `BASE_PAUSE`, or changing
   `target_tool`. A second failed recovery must keep the original saved point.
3. For the first pause during a print, check the existing `error_state`. On a
   **manual** pause (`error_state == 0`), save
   `printer.medusahc.current_tool` to the existing `GLOBAL_STATE.target_tool`.
   On a **tool-change failure**, leave `target_tool` alone: `SET` or `DROP`
   already set it to the intended tool. Do not add a new `resume_tool` variable.
4. Call `BASE_PAUSE` **before** the printer-specific Z lift and XY parking
   moves. That saves the real print position for a manual pause. Core replaces
   this saved state with the pre-change state if a tool change failed.
5. In `RESUME`, while `printer.pause_resume.is_paused` is true, read the saved
   `target_tool` and call only `MHC_RESUME T={target_tool}`. Remove the old
   inline `G28`, `CLOSE`, `SET`, E moves, `BASE_RESUME` and tool-offset call from
   this branch; `MHC_RESUME` owns that sequence and calls `BASE_RESUME` only
   after successful preparation. Do not clear `error_state` before it runs.
6. Preserve your existing notification and non-print behavior as appropriate.
   Use the exact macro name on **your** printer: some configs use
   `GLOBAL_STATE`, others `_GLOBAL_STATE`. The `printer["gcode_macro ..."]`
   lookup and `SET_GCODE_VARIABLE MACRO=...` must refer to the same one.

The [complete PAUSE/RESUME example](../config/MedusaHC/macros_examples.cfg)
uses the standard Duender layout: `_GLOBAL_STATE` and parking at Y220/X0.
Adapt the steps above to your own macros if your printer uses different
coordinates or macro names.

After editing, restart Klipper while the printer is idle so the new Python
module and macros load together. An installer update alone leaves the active
macros unchanged; mixing the old `RESUME` macro with the new controller keeps
the old recovery behavior.

## Recovery behavior

The controller records the print's G-code state before normal SET/DROP motion.
An error during a print sets `GLOBAL_STATE.error_state`, latches
`medusahc.sensor_error` and `medusahc.last_error`, then invokes `PAUSE` once.
It no longer adds a Y move before the printer's park. Another failure while
already paused does not invoke `PAUSE` again or overwrite the saved point.
Manual sensor movement outside SET/DROP leaves `sensor_error` false;
`current_tool = -2` alone means the physical state is undetermined.

On a manual pause, `MHC_RESUME` compares the mounted tool with the saved
`target_tool`. If they match, it returns to the print position without XY
homing or priming. If they differ, or the pause followed a failed tool change,
it raises Z if necessary, homes XY, closes the feeder and runs the normal SET
path. The target tool is primed and brush-cleaned during this path even while
Klipper reports the print as paused, including when that tool is already
mounted. Preparation requires the target tool to be above 190 C. A failed SET
leaves the printer paused; it cannot reach `BASE_RESUME`.

For failed-change recovery, Core restores G-code modes, E position and tool
offset while keeping the head at the safe exit position after cleaning. It
does not return to the old tool's last print XY. The next commands in the
print file move the new tool to its destination. **The slicer's G-code must
set the correct Z before the first extrusion after a tool change.** The
multi-tool sample files checked for this release do so; check other slicer
profiles before relying on this path. For a manual pause, the head travels
above the saved print XY, then `BASE_RESUME VELOCITY=30` lowers it to the saved
layer. A Z jog through the printer menu does not overwrite that saved layer;
recovery raises a lowered Z before any XY homing.

Core currently copies Klipper's `gcode_move.saved_states["PAUSE_STATE"]` to
preserve the pre-change G-code and E context. This uses Klipper's internal
saved-state representation and should be checked when updating Klipper.

## Printer checks

With the actual slicer profile, verify in this order: manual PAUSE/RESUME with
the same tool; manual pause after changing the mounted tool; a failed pickup;
one more failed RESUME while still paused; then a successful recovery. Check
that repeat failure does not move away from the park, the recovered tool primes
and cleans, the next file move goes to the new tool's location without visiting
the old tool's print XY, and Z reaches the intended layer before extrusion.

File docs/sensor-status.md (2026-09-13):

# Sensor status for interface integrations

Read `medusahc.sensor_error` to display sensor validation failures, and
`medusahc.last_error` for the explanation. The flag is latched when SET/DROP
rejects an ambiguous initial state, or when sensors do not confirm the result
of pick/drop within the configured timeout. It clears when the next valid
SET/DROP request is accepted (or Klipper restarts), alongside `last_error`.
Changing sensors by hand does not clear a recorded operation failure.

`current_tool` is live sensor information: -1 means all tools are parked,
0 and above identify the attached tool, and -2 means undetermined. An
undetermined state alone is not an error, either during a swap or while
manually rearranging hotends. `operation` describes the current procedure.
The `pin_watch` status and tool identification algorithm remain unchanged.

Sensor status does not diagnose electrical pin faults. PAUSE/RESUME recovery
uses the same flag to prevent a failed tool change from continuing the print;
see `recovery.md` for the printer-check sequence.

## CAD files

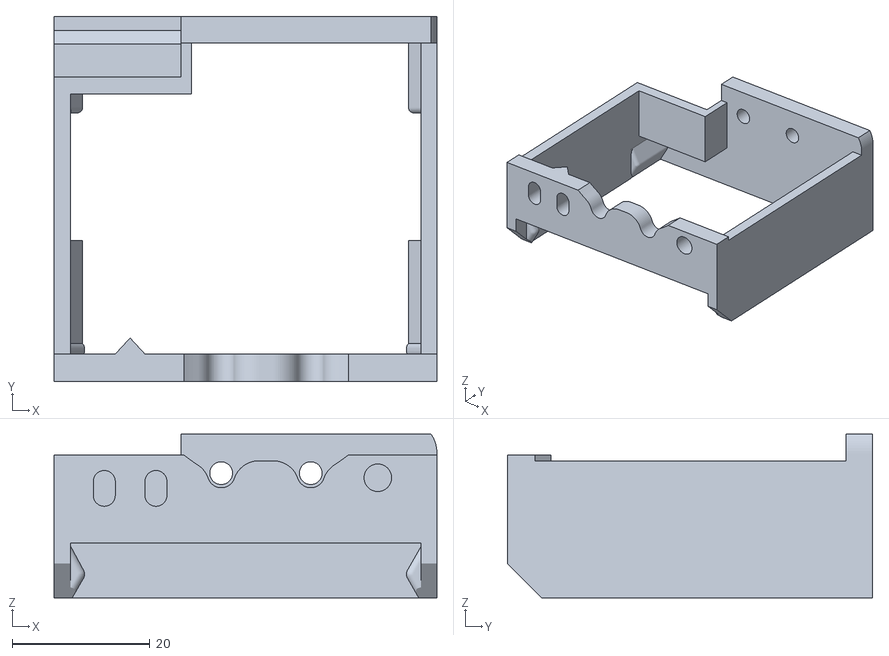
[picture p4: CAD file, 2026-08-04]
STLs/Base/Base_Bin_Main V-Back.stl
55.6 x 53.0 x 23.8

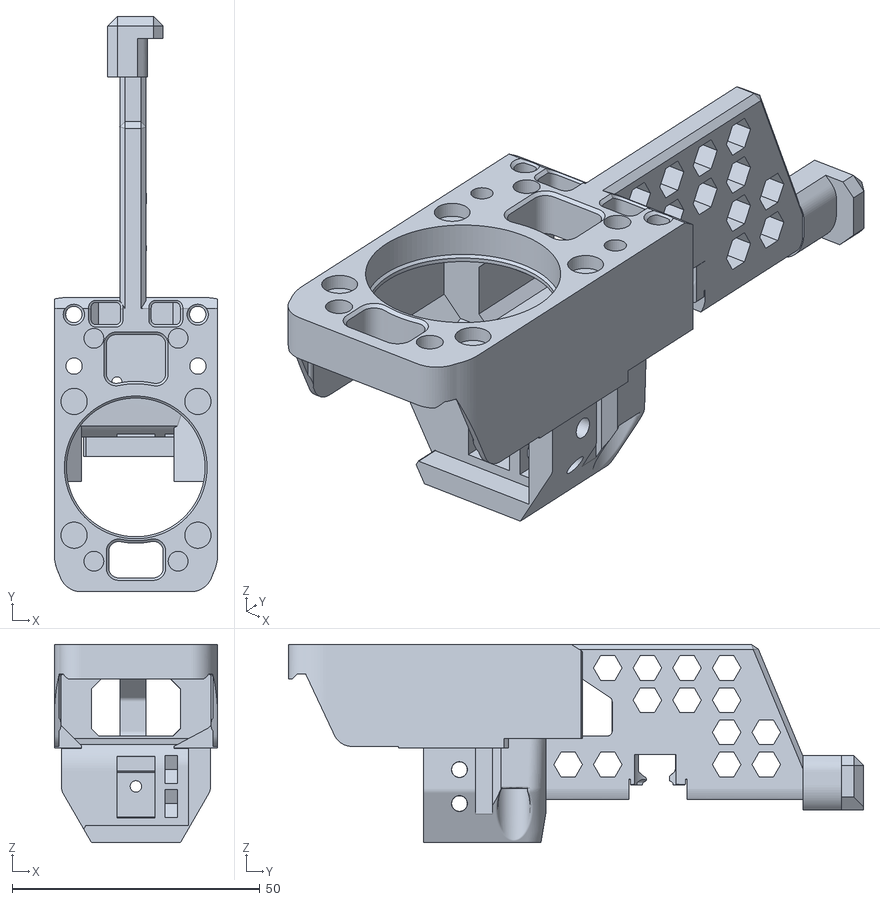
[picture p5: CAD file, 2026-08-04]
STLs/Hotend/Hotend_Main Bambu.stl
33.0 x 116.2 x 40.0

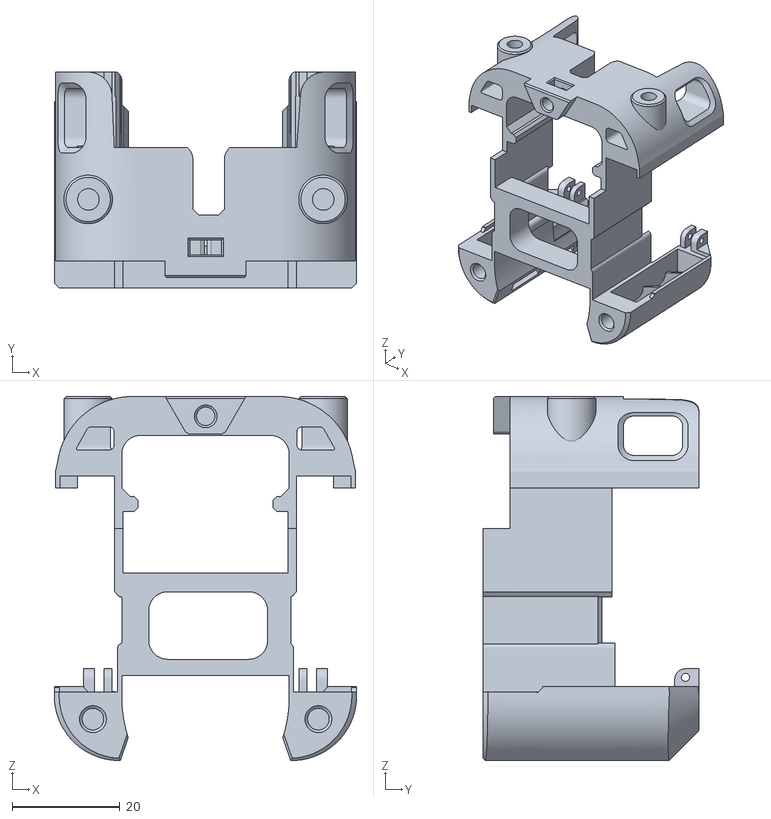
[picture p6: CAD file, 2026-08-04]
STLs/Toolhead/Extruder Main.stl
56.0 x 40.0 x 67.4

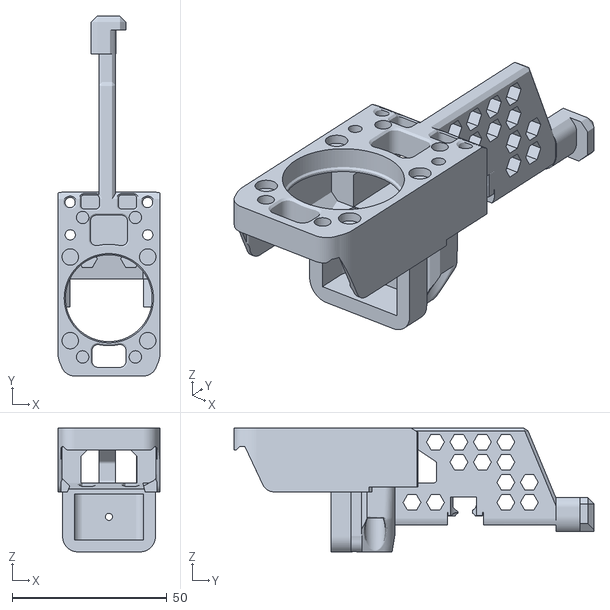
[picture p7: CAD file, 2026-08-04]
STLs/Hotend/Hotend_Main TZ.stl
33.0 x 116.2 x 40.0

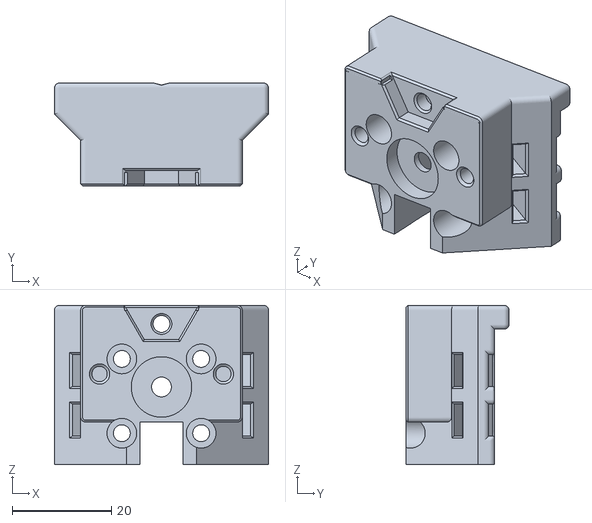
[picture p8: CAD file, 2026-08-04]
STLs/Toolhead/MGN9H Mount Main.stl
43.2 x 20.8 x 32.2

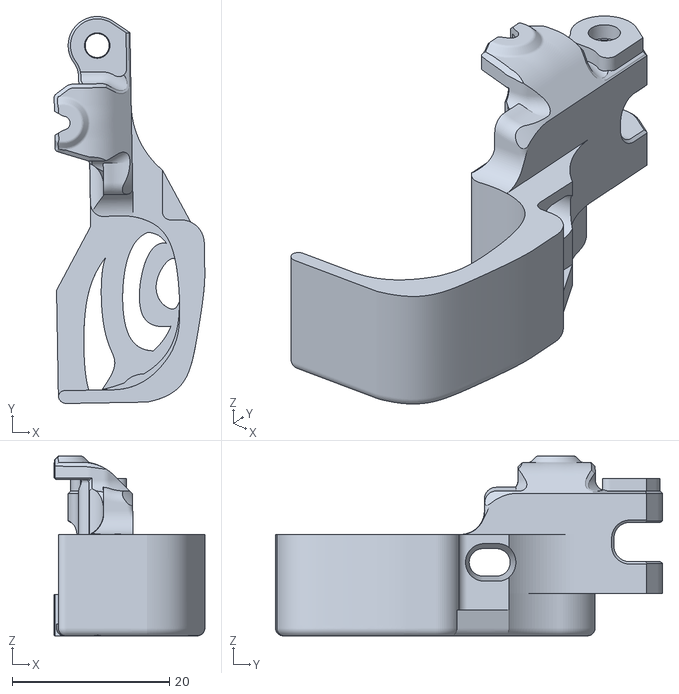
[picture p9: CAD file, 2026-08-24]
STLs/Feeder/Feeder Lever Main.stl
19.2 x 49.3 x 22.9

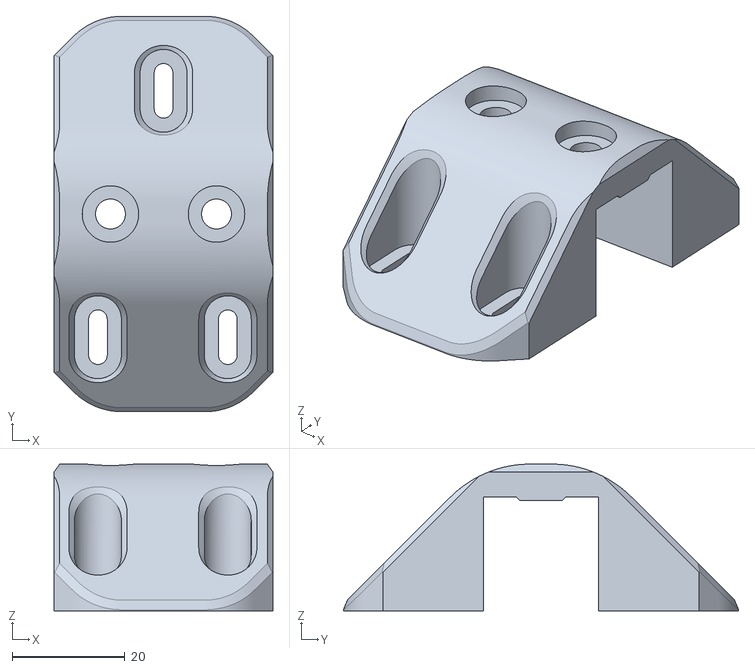
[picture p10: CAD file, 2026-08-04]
STLs/Base/Base_Mount_Main.stl
38.8 x 70.0 x 26.0

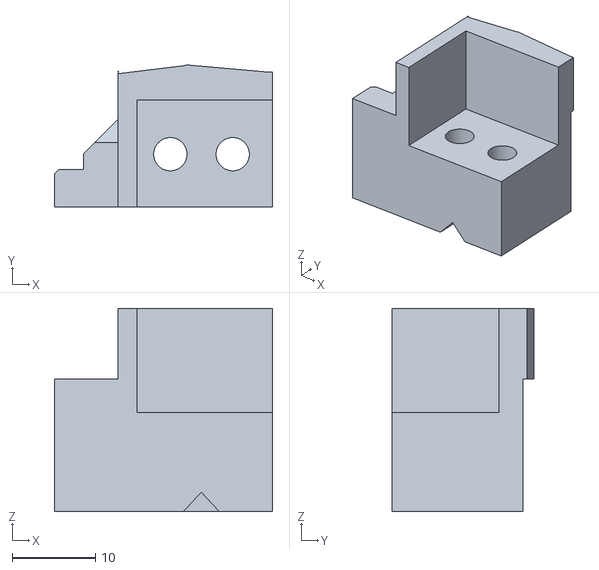
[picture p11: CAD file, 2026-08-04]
STLs/Base/Nozzle_Close_Clean_Main.stl
26.2 x 17.1 x 24.4

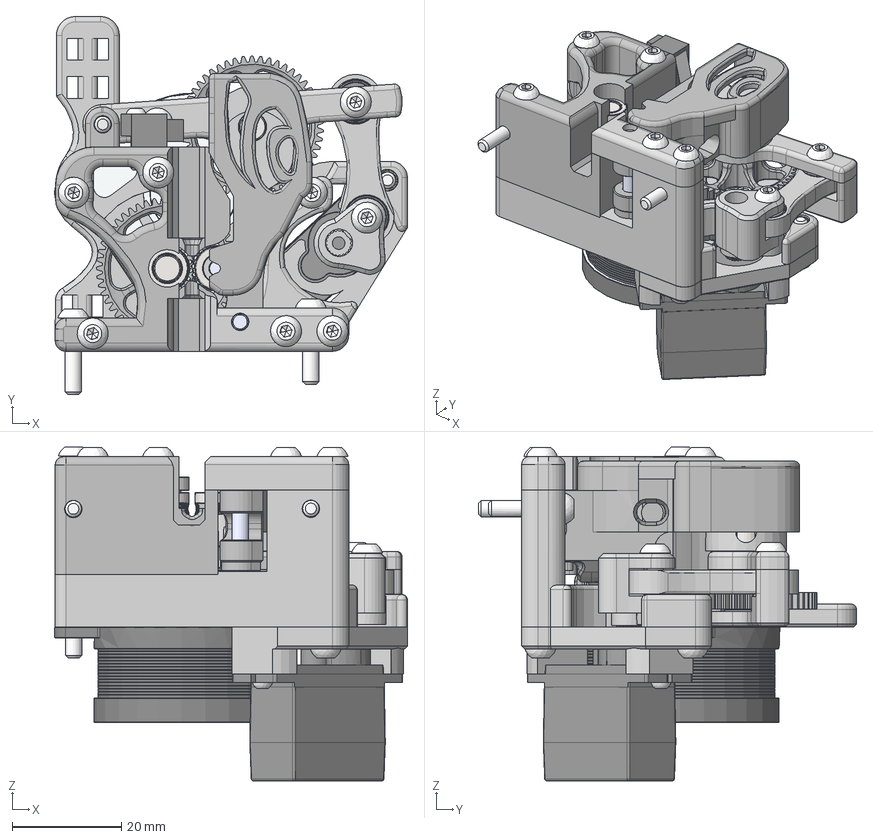
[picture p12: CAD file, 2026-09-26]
STEP/MedusaHC_Feeder_Lever_MOD.step
64.6 x 69.2 x 61.1 mm
Feeder Small Cover
sherpa_mini_gear_50t_sl_7mm^drive_core_sherpa_mini_a3_r17 x 2
MR85-2RS^drive_core_sherpa_mini_a3_r17 x 4
shaft^drive_core_sherpa_mini_a3_r17 x 2
Feeder Lever 2
Opener Bearing
Feeder Opener (1)
Feeder Lever Mail
filament_gear^drive_core_sherpa_mini_a3_r17
idler_gear^idler_gear_assy_sherpa_mini_a3_r17
shaft^idler_gear_assy_sherpa_mini_a3_r17
idler_pin^sherpa_mini_a3_r17
NEMA14_10t^sherpa_mini_a3_r17
Servo
Servo_Mount
limit switch
M3X8Pan Head Screw (2) (1) (2) x 7
M3X30Pan Head Screw (1) (1) (1) (1) (1) (1) (1) (1) (1) (1) (1) (1) ( 1)
M3X20Pan Head Screw (1) (1)
M3X12Pan Head Screw (1) x 2
M3X30Pan Head Screw (1) x 2
M3 Insert (1) x 8
M2 Insert (3)
M2X10 Screw (3) x 4
Pins (2)
Feeder Body 2
Feeder Body 1
Feeder Lever Bearings
Feeder Lever 4

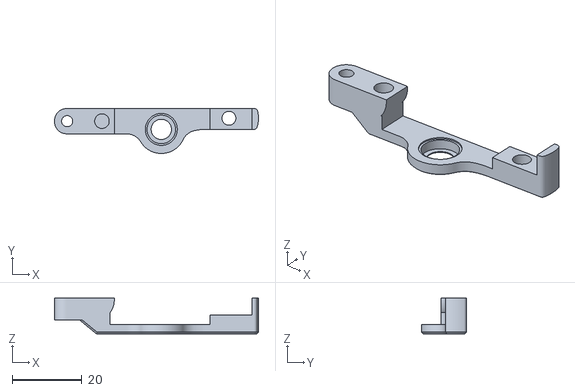
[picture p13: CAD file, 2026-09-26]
STLs/Feeder/Feeder Lever 2.stl
58.6 x 12.9 x 10.3

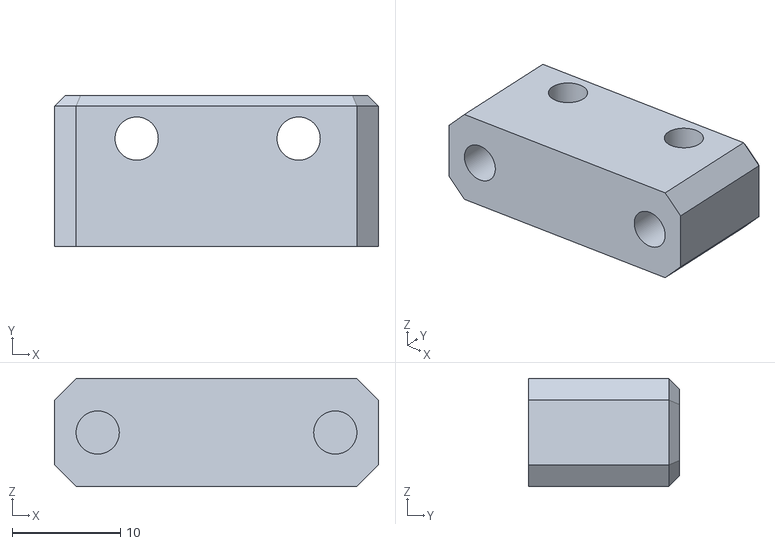
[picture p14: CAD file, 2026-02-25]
STLs/SexBall Mount/SexBall_mount.stl
30.0 x 14.0 x 10.0

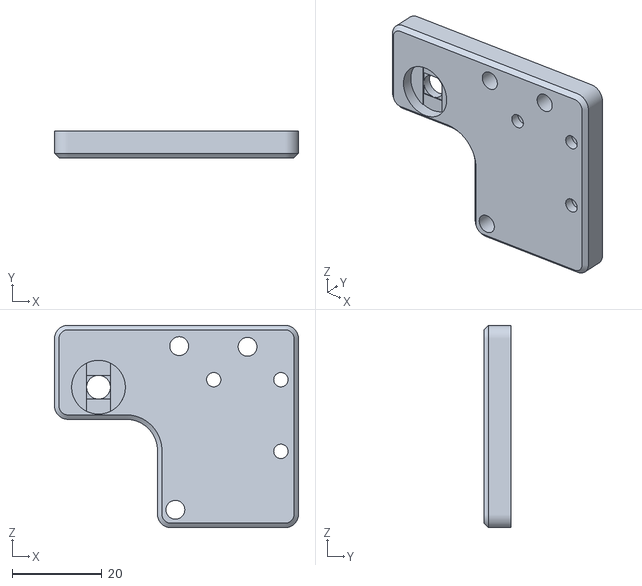
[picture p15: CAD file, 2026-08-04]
STLs/V-Back Mounts/X-Back 1 MGN9H R.stl
54.5 x 6.00 x 45.2

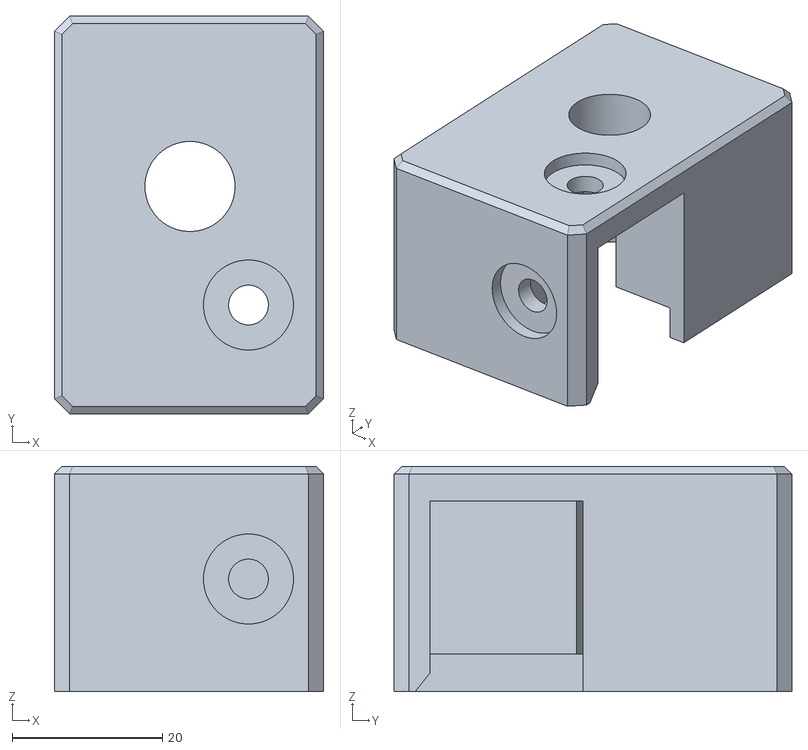
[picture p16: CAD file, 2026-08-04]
STLs/V-Front Mounts/Base_Profile_Mount_L.stl
35.9 x 53.0 x 30.0

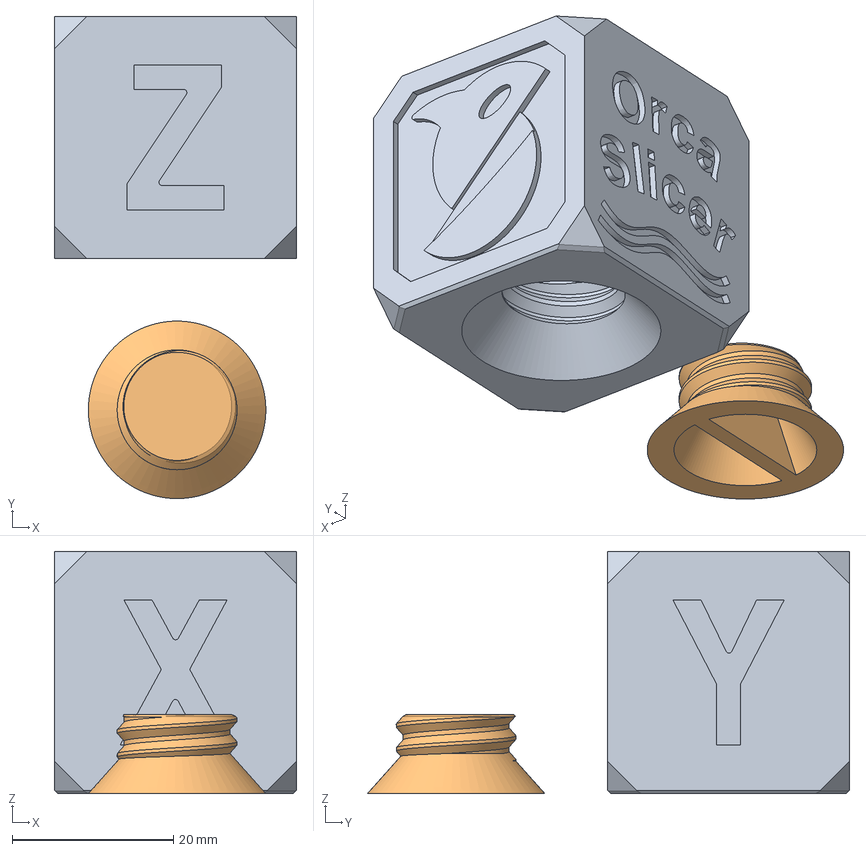
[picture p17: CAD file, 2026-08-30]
Slicer/4rcaCube.3mf
30.0 x 59.8 x 30.0 mm

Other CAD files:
STLs/Base/Base_Bin_Main V-Front.stl
Slicer/4rcaCube_orca_project.3mf
STLs/Base/PTFE Cleaner.stl
STLs/Feeder/Feeder Body 1.stl
STLs/Base/Base_Bin.stl
STLs/Base/Base_Mount_Plate.stl
STLs/Base/Side PTFE Holder.stl
STLs/Base/Wire Holder M6-M6.stl
STLs/Base/Wire_Holder M6-M10.stl
STLs/Base/Wire_Holder PU4.stl
STLs/Feeder/Feeder Body 2.stl
STLs/Feeder/Feeder Lever 2 Cover.stl
STLs/Feeder/Feeder Lever 3.stl
STLs/Feeder/Feeder Lever 4.stl
STLs/Feeder/Feeder Opener (1).stl
STLs/Feeder/Feeder Opener.stl
STLs/Feeder/Feeder Small Cover.stl
STLs/Feeder/Servo_Mount.stl
STLs/SexBall Mount/Ball_adapter.stl
STLs/SexBall Mount/Probe_Plate.stl
STLs/SexBall Mount/Probe_hold.stl
STLs/Toolhead/MGN9H Mount EDDY ADXL.stl
STLs/V-Back Mounts/MedusaHC Back Mount M3.stl
STLs/V-Back Mounts/MedusaHC Back Mount M5.stl
STLs/V-Back Mounts/X-Back 1 MGN9H L.stl
STLs/V-Back Mounts/X-Back 2 MGN9H L.stl
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

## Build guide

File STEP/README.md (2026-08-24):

# STEP assembly

`MedusaHC V0.2.step` is a visual and mechanical reference for both supported layouts.

The assembly demonstrates five tools in the V-Front layout and four tools in the V-Back layout. The supplied Klipper configuration and slicer examples are configured for four tools.

Verify the actual printer geometry, clearances, mounting positions, and tool count before manufacturing parts from this assembly.

## Experimental feeder assembly

`MedusaHC_Feeder_Lever_MOD.step` contains the new lever-driven feeder as a separate assembly. This experimental feeder is not yet included in the main `MedusaHC V0.2.step` assembly.

The printable files in `STLs/Feeder` have already been updated to this new feeder version. The previous feeder parts are no longer provided as separate STL files; users who need the old design can obtain them from the full `MedusaHC V0.2.step` assembly, where the previous feeder is still included.

The new version is currently being tested. If it proves reliable, it will replace the current feeder as the main version and will be added to the full MedusaHC STEP assembly.

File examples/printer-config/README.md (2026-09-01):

# Supplementary printer configuration examples

This folder contains supplementary Duender printer examples such as
`printer.cfg`, Eddy/BLTouch configuration, sensorless homing, ADXL, and an
example saved-variables file. These files are not installed automatically.

The canonical MedusaHC Core configuration installed into
`~/printer_data/config/MedusaHC/` is stored in `config/MedusaHC/` at the
repository root.

The supplied configuration is a **4-tool V-Front Duender example**. It is not a universal drop-in printer configuration. Before use, check all MCU identifiers, pins, axis limits, homing directions, TMC settings, PID values, probe offsets, dock coordinates, and parking positions.

The main MedusaHC files in the repository's `config/MedusaHC/` directory are:

- `MHC_config.cfg` — tool sensors, shared extruder hardware, heaters, fans, servo, and tool commands.
- `MHC_variables.cfg` — tool count, layout orientation, dock coordinates, cleaning/priming settings, and stored offsets.
- `MHC_macros.cfg` — the public macro interface and small compatibility wrappers for the Python controller.
- `medusahc.py` from `klippy/extras/` — pickup, drop, feeder, cleaning, priming, error handling, and offset logic.
- `pin_watch.py` from `klippy/extras/` — real-time tool sensor monitoring.

## Layout selection

Set `variable_tools_direction` in `config/MedusaHC/MHC_variables.cfg`:

- `1` — V-Front;
- `-1` — V-Back.

Then enter the actual X/Y coordinates for the installed docks. Pickup, drop, cleaning, and priming directions are derived automatically from `variable_tools_direction`. Parking coordinates in printer-level macros must still be adjusted separately.

## Probe selection

The example enables native Klipper Eddy support through `eddy_config.cfg`.

`bltouch.cfg` is an alternative backup configuration. Do not enable Eddy and BLTouch probe sections at the same time without resolving duplicate sections and pins. A BLTouch setup also requires manual review of `START_PRINT`, including the Eddy-specific `TAP_BASE_TOOL` call.

Tool-offset auto-calibration is intentionally not bundled into this base
configuration. Install the optional MedusaHC-Calibrate module when automatic
SexBall/contact, Eddy Tap Z, or Eddy Tap + EddySeek XYZ calibration is needed.

## External components

Some example sections depend on software installed separately:

- `pin_watch.py`, which must be copied to the Klipper `klippy/extras` directory;
- `medusahc.py`, which must be copied to the same Klipper `klippy/extras` directory;
- optional klipper-tmc-autotune;
- standard installation-specific files such as `mainsail.cfg` and `timelapse.cfg`.

`pin_watch.py` retains optional, disabled-by-default compatibility
synchronization with `klipper-toolchanger`. MedusaHC does not install or
require that plugin. A minimal optional configuration is documented in the
main project README.

Camera-assisted tool calibration is not currently included. A new native or
adapted implementation may be added later.

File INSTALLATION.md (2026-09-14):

# MedusaHC Core installation

This page covers the Python-based MedusaHC Core from the `main` branch. The
installer is deliberately semi-manual: it places the required files in a
standard Klipper layout, but it does not attempt to rewrite an existing printer
configuration.

> [!WARNING]
> Do not install, update, remove, or restart Klipper during a print. Keep a
> backup of the working printer configuration before enabling MedusaHC.

## Requirements

- An existing Klipper installation.
- A normal `printer_data/config` directory.
- `curl` and `tar` for the online installer.
- Permission to write to the Klipper extras and printer configuration
  directories. Run the command as the printer user when those directories are
  owned by that user. Use `sudo` only if the local installation requires it.

The installer normally detects the current user and uses:

- `~/klipper/klippy/extras/`
- `~/printer_data/config/`
- `~/printer_data/config/MedusaHC/`

## Install

Run this command in an SSH terminal on the printer:

```bash
bash -c "$(curl -fsSL https://raw.githubusercontent.com/Irbis3D/MedusaHC/main/install-online.sh)"
```

The installer:

1. Downloads the current `main` branch into a temporary directory.
2. Copies `medusahc.py` and `pin_watch.py` into Klipper's `klippy/extras`
   directory.
3. Creates `~/printer_data/config/MedusaHC/`.
4. Places editable example configuration files in that directory.
5. Prints the manual configuration steps that remain.

The optional macro and purge examples are installed as `macros_examples.cfg`
and `Line_Purge_examples.cfg`. These files are not included automatically and
can be copied from selectively if needed.

Core requires a `_HOME_REQUEST` (or `HOME_REQUEST`) macro. If your configuration
does not define one, copy `_HOME_REQUEST` from `macros_examples.cfg` into an
included configuration file and adapt its homing checks to your printer.
Do not include all the examples just to obtain this helper: they also define
print start, end and pause macros which may conflict with your own.

It does **not**:

- edit `printer.cfg`;
- restart Klipper or any other service;
- modify Moonraker;
- overwrite live files in an existing `MedusaHC` configuration directory;
- migrate settings from an older installation.

Reinstalling with a retained `MHC_config.cfg` and `MHC_variables.cfg` restores
the Python modules and places new examples in `upstream-examples`, just like
update. An unrelated or incomplete existing directory is rejected.

The supplied configuration is an example for a four-tool V-Front Duender with
a BTT Manta M8P V2.0. It is not a universal ready-to-run printer configuration.

Before enabling it, review every MCU name, pin, thermistor, heater, fan, PID
value, tool sensor, tool count, dock coordinate, axis limit, offset, cleaning
position, and priming position.

`MHC_config.cfg` includes complete hotend definitions, including the primary
`[extruder]` section. If the same sections already exist in `printer.cfg` or an
included file, move, remove, or comment the duplicates manually. Klipper cannot
load two sections with the same name.

Only after resolving those conflicts, add this line to `printer.cfg`:

```ini
[include MedusaHC/MHC_config.cfg]
```

Then review the Klipper configuration and perform a firmware restart while the
printer is idle.

## Status

```bash
bash -c "$(curl -fsSL https://raw.githubusercontent.com/Irbis3D/MedusaHC/main/install-online.sh)" -- status
```

This reports whether the two Python modules and the MedusaHC configuration
directory are present. It does not change anything.

## Update

```bash
bash -c "$(curl -fsSL https://raw.githubusercontent.com/Irbis3D/MedusaHC/main/install-online.sh)" -- update
```

An update replaces only `medusahc.py` and `pin_watch.py`. The active user
configuration is preserved. Current example files are written to:

```text
~/printer_data/config/MedusaHC/upstream-examples/
```

They are references for manual comparison and are not included automatically.
Klipper is not restarted by the updater.

The Python controller registers only `MHC_*` G-code commands. If a custom
configuration called the removed unprefixed Python aliases, use the supplied
macro wrappers or the controller commands instead: `DROP` → `_DROP` or
`MHC_DROP`, `TOOL_OFFSET_T` → `_TOOL_OFFSET_T` or `MHC_TOOL_OFFSET`,
`LAYER_SET` → `_LAYER_SET` or `MHC_LAYER_SET`, and `PRIME_FLAGS_SET` →
`_PRIME_FLAGS_SET`. Update MedusaHC Control before Core if Control is installed;
the matching Control release applies active-tool offsets through
`MHC_TOOL_OFFSET`.

If this update adds `MHC_RESUME`, also update your active `PAUSE` and `RESUME`
macros before restarting Klipper. The updater preserves them, and the old
`RESUME` macro will keep its old recovery behavior. Follow the
[PAUSE/RESUME migration guide](docs/recovery.md); keep your printer's own
parking coordinates and macro names.

## Uninstall

First remove dependent modules such as MedusaHC-Calibrate, MedusaHC Control,
and MedusaHC Mainsail. The Core uninstaller refuses to continue while detected
dependent components remain.

Remove the Python modules while keeping all configuration:

```bash
bash -c "$(curl -fsSL https://raw.githubusercontent.com/Irbis3D/MedusaHC/main/install-online.sh)" -- uninstall
```

Afterward, manually remove or comment this line in `printer.cfg` before
restarting Klipper:

```ini
[include MedusaHC/MHC_config.cfg]
```

To also delete the complete `~/printer_data/config/MedusaHC/` directory, use:

```bash
bash -c "$(curl -fsSL https://raw.githubusercontent.com/Irbis3D/MedusaHC/main/install-online.sh)" -- uninstall --purge
```

The purge action asks for confirmation and is irreversible unless a separate
backup exists. It does not edit `printer.cfg` for you.

## Manual installation

Clone or download the repository, then copy the two Klipper modules:

```bash
git clone https://github.com/Irbis3D/MedusaHC.git ~/MedusaHC-source
install -m 0644 ~/MedusaHC-source/klippy/extras/medusahc.py ~/klipper/klippy/extras/medusahc.py
install -m 0644 ~/MedusaHC-source/klippy/extras/pin_watch.py ~/klipper/klippy/extras/pin_watch.py
mkdir -p ~/printer_data/config/MedusaHC
cp -a ~/MedusaHC-source/config/MedusaHC/. ~/printer_data/config/MedusaHC/
```

This is the same source layout and the same file copy performed by the
automatic installer. The copied `MHC_config.cfg` already starts with the
required relative includes:

```ini
[include MHC_variables.cfg]
[include MHC_macros.cfg]
```

Do not add a second copy of them.

Configure the files for the actual printer, resolve duplicate Klipper sections,
and finally add `[include MedusaHC/MHC_config.cfg]` to `printer.cfg`.

Manual removal is the reverse operation: remove the include from `printer.cfg`,
delete `medusahc.py` and `pin_watch.py` from `klippy/extras`, and delete the
`MedusaHC` configuration directory only if its settings are no longer needed.

## Non-standard paths

The local `install.sh` also accepts path overrides through environment
variables:

```bash
MEDUSAHC_USER=biqu \
KLIPPER_DIR=/home/biqu/klipper \
PRINTER_CONFIG_DIR=/home/biqu/printer_data/config \
bash ./install.sh install
```

`MEDUSAHC_CONFIG_DIR` can override the destination configuration directory.
Keep it inside the printer configuration directory if purge support is needed.

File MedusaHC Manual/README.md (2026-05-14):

[MedusaHC manual (work in progress)](https://drive.google.com/file/d/1KkSGdeQZzl4gnCMKlBloHfCNIlD4JwAP/view)

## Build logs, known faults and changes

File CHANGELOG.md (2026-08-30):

# MedusaHC changelog

This file summarizes the major public changes between MedusaHC releases. The project is still in beta, so every configuration must be reviewed and adapted to the actual printer before use.

## Unreleased

- Made the tested Python tool-change controller the default implementation on
  `main` and preserved the final macro implementation in the frozen
  `legacy-macros` branch.
- Hid internal state and compatibility helpers from the Mainsail macro panel
  while retaining the established public commands and slicer compatibility.
- Moved automatic tool-offset calibration into the independent
  MedusaHC-Calibrate module.
- Removed the bundled legacy klipper-toolchanger calibration and example
  configuration files from the base MedusaHC setup.
- Kept optional pin-watch synchronization with klipper-toolchanger, disabled by
  default for users who configure that plugin separately.
- The base configuration now contains normal MedusaHC operation and native
  printer probe configuration; optional calibration modules can be installed or
  removed independently.
- Added explicit per-tool first-use retract settings to the configuration
  template for the planned Python-controller migration.

## V0.2 Beta — 2026-08-04

V0.2 is a major mechanical, configuration, calibration, and repository update. It adds two supported dock orientations, refreshes the common tool hardware, replaces Eddy-ng with native Klipper Eddy tap support, and provides a new four-tool Duender example configuration.

### Mechanical layouts

- Added **V-Front** and **V-Back** dock layouts.
- V-Front places the docks in front of the print area. It provides more available space for tools and is generally easier to adapt to Voron-style and other CoreXY printers.
- V-Back places the docks behind the print area, closer to the XY motors. The shorter effective belt path reduces the influence of belt elasticity during docking and keeps the front of the printer open and easy to observe.
- Both layouts use the same main MedusaHC macros and common Base, Feeder, Hotend, and Toolhead parts.
- The full STEP assembly demonstrates five tools in the V-Front layout and four tools in the V-Back layout. The supplied Klipper configuration and OrcaSlicer files are configured for four tools.

### Duender mounting compatibility

- Current layout-specific mounts are designed for a Duender with **MGN9H rails on the XY axes**.
- MGN12H installations require the MedusaHC mounting system to be raised and the final geometry to be checked on the actual printer.
- V-Front can use adapters with the standard Duender front mounts or the included GN500 front mounts with a profile opening.
- For V-Back, the standard Duender front mounts remain installed while the docks attach to the rear profile with new mounting parts.
- V-Back requires the complete X axis to face rearward, the X rail to move to the opposite side of the profile, and the belts to run behind the X profile.
- The current V-Back toolhead belt clamp may require several belt teeth to be removed in the clamped section so the carriage can seat fully. A small amount of cyanoacrylate can be used to reduce the risk of slipping. This is a temporary assembly solution.
- Depending on the available rear clearance, the complete Z axis and bed may need to be shifted forward.

### Printable parts and reference files

- Added separate `V-Front Mounts` and `V-Back Mounts` folders.
- Added new front and rear dock mounts and reversed MGN9H X-axis mounts.
- Retained the left and right glue-on adapters for installing MedusaHC on the standard Duender front mounts.
- Added separate V-Front and V-Back main bin parts.
- Updated the common dock base, bin, mounting plate, feeder, toolhead, and carriage parts.
- Added updated nozzle-cleaning, PTFE-cleaning, priming, PTFE-routing, and wire-management parts.
- Added Bambu-style and TZ hotend body variants.
- Added an Eddy and ADXL-compatible MGN9H toolhead mount.
- Moved the servo and MG90S opening mechanism parts to the Feeder folder.
- Retained the SexBall mounting parts for contact-sensor calibration.
- Replaced the separate V0.1 STEP component files with one complete V0.2 reference assembly.
- Added V-Front and V-Back reference renders.

### Four-tool configuration

- Reworked the example configuration for a standard Duender with four front-mounted tools.
- Tools are numbered normally from `T0` through `T3` in both configuration variables and klipper-toolchanger definitions.
- Updated the example X dock positions and side clearances for the four-tool Duender layout.
- Added `variable_tools_direction` to select the dock orientation:
  - `1` for V-Front;
  - `-1` for V-Back.
- Pickup, drop, cleaning, and priming movement directions are derived automatically from `variable_tools_direction`.
- Users still need to enter the actual dock coordinates and separately configure all printer-level parking positions for the selected layout.
- Updated `printer.cfg`, sensorless homing, axis limits, and parking examples for the four-tool front layout.
- Retained BLTouch as an optional backup configuration. BLTouch users must manually review duplicate probe sections, pins, and the Eddy-specific `TAP_BASE_TOOL` call in `START_PRINT`.

### Feeder, cleaning, and priming behavior

- Updated the feeder `OPEN` and `CLOSE` movements to match the current mechanism.
- Updated extruder-current handling for the current feeder and motor arrangement.
- Reworked the cleaning and priming movement variables and macros for the new base system.
- Cleaning and priming positions now follow the same layout-relative geometry as the latch position.
- Updated per-tool priming, cleaning, retract, and first-use priming variables.
- Updated pause, resume, cancellation, tool-change recovery, and safe-movement behavior.

### Eddy probing and Z calibration

- Removed the Eddy-ng configuration and the modified `probe_eddy_ng.py` Klipper module.
- Added `eddy_config.cfg` for native Klipper Eddy current probe and tap support.
- Renamed and reworked the old Eddy feature macros as `eddy_features.cfg`.
- Added `TOOL_Z_CALIBRATION` for automatic Z-only calibration of `T0` through `T3` with native Eddy tap probing.
- T0 is used as the Z reference. Calculated tool Z offsets are saved to `saved_vars.cfg` and restored during initialization.
- The new Eddy mount position differs from the previous version. Probe installation height and all probing movements must be verified before automatic calibration.

### Full X/Y/Z tool calibration

- Full automatic tool-offset calibration now uses the stock **klipper-toolchanger** calibration system.
- SexBall, Nudge, and similar contact sensors supported by klipper-toolchanger can be used for X, Y, and Z calibration.
- The stock `tools_calibrate.py` is used without modification, allowing klipper-toolchanger to be updated normally.
- Added automatic transfer of the latest klipper-toolchanger calibration results into MedusaHC tool-offset variables and `saved_vars.cfg`.
- Updated `CALIBRATE_AND_SAVE_OFFSETS` to select each tool, reset the selected tool offset at the correct point in the loop, run calibration, and save the results.
- Without a contact calibration sensor, native Eddy tap can calibrate Z only. X and Y must be calibrated manually or by another suitable method.

### OrcaSlicer and post-processing

- Added two updated four-tool OrcaSlicer 3MF projects.
- Added a separate four-tool Duender/MedusaHC printer preset.
- Removed the unused `EXTRUDER4_TEMP` and `EXTRUDER5_TEMP` parameters from the supplied start G-code.
- Removed computer-specific post-processing paths from the public 3MF projects.
- Retained `SET_FINISH.py` and added `SET_FINISH_Snapmaker_Orca.py`.
- Post-processing script paths must be configured locally by each user.

### Documentation and repository organization

- Expanded the main README with V-Front/V-Back selection, Duender mounting requirements, probe choices, calibration procedures, and known limitations.
- Added a short English README to every public project folder.
- Reorganized `Config` as `Macros` and replaced the old `3MF` folder with `Slicer`.
- Added dedicated `Images` and `STEP` folders.
- Marked STL, STEP, 3MF, PNG, and ZIP files as binary in Git attributes.
- Preserved the existing manual, BOM links, GPLv3 license, and affiliate purchasing links.

### Removed legacy files

- Removed the V0.1 OrcaSlicer projects from the current branch.
- Removed the separate V0.1 STEP component files from the current branch.
- Removed obsolete base, brush, nozzle-close, feeder, and toolhead models that were replaced by V0.2 parts.
- Removed `eddy_ng.cfg`, `eddy_ng_features.cfg`, and `probe_eddy_ng.py`.
- Removed the old optional `KlipperScreen.conf` example.

The V0.1 files remain available through the Git history at commit `0136d07`.

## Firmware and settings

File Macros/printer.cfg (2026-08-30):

[include mainsail.cfg]
#[include Adaptive_Mesh.cfg]
[include Line_Purge.cfg]
[include macros.cfg]
[include sensorless.cfg]
[include timelapse.cfg]
[exclude_object]
#[include moonraker_obico_macros.cfg]
[include MHC_variables.cfg]

[include eddy_config.cfg]

#[include adxl.cfg]
#[include bltouch.cfg]

[gcode_arcs]
resolution: 0.1

[mcu CB2]
serial: /tmp/klipper_host_mcu

[mcu]
canbus_uuid: ec86e7529fab

[printer]
kinematics: corexy
max_velocity: 500
max_accel: 16000
max_z_velocity: 40
max_z_accel: 180
minimum_cruise_ratio: 0

[input_shaper]
shaper_type_x: ei
shaper_freq_x: 90.0
shaper_type_y: ei
shaper_freq_y: 80.6

[stepper_x]
step_pin: PE6
dir_pin: PE5
enable_pin: !PC14
microsteps: 32
rotation_distance: 39.8
endstop_pin: tmc2209_stepper_x:virtual_endstop
position_endstop: -10
position_min: -10
position_max: 250
homing_speed: 80
homing_retract_dist: 0

[stepper_y]
step_pin: PE2
dir_pin: !PE1
enable_pin: !PE4
microsteps: 32
rotation_distance: 39.8
endstop_pin: tmc2209_stepper_y:virtual_endstop
position_min: -59
position_endstop: 230
position_max: 230
homing_speed: 80
homing_retract_dist: 0

[stepper_z]
step_pin: PB8
dir_pin: !PB7
enable_pin: !PE0
microsteps: 128
rotation_distance: 8

#Bltouch or Eddy
endstop_pin: probe:z_virtual_endstop

#Regular Endstop
#endstop_pin: PF2
#position_endstop: 0

position_max: 240
position_min: -50
homing_speed: 25
homing_retract_dist: 0

[stepper_z1]
step_pin: PB4
dir_pin: !PB3
enable_pin: !PB6
microsteps: 128
rotation_distance: 8

#sensor_type:MAX31865
#sensor_pin: PA4
#spi_bus: spi1
#rtd_nominal_r: 100
#rtd_reference_r: 430
#rtd_num_of_wires: 2

#[filament_switch_sensor material_0]
#switch_pin: PC2


[heater_bed]
heater_pin: PF5
sensor_pin: PB1 # TB
sensor_type: EPCOS 100K B57560G104F
control: pid
pid_Kp = 75.448
pid_Ki = 1.935
pid_Kd = 735.620
min_temp: 0
max_temp: 130

[fan]
pin: PA4

#[controller_fan driver_fan]
#pin: PC11
#stepper: stepper_x
#heater: extruder

[temperature_sensor MCU]
sensor_type: temperature_mcu

[temperature_sensor CB2]
sensor_type: temperature_host

#[temperature_fan CB2_fan]
#pin: !PC11
#sensor_type: temperature_host
#min_temp: 0
#max_temp: 90
#target_temp: 40.0
#control: watermark

[z_tilt]
z_positions:
    -8, 125
    243, 125
points:
    40, 100
    210, 100
speed: 150
horizontal_move_z: 2


[bed_screws]
screw1: 30.5, 37
screw2: 30.5, 207
screw3: 204.5, 207
screw4: 204.5, 37

#[heater_fan SoC_fan]
#pin: CB1:gpio79
#pin: RPI:gpio26

########################################
# TMC2209 configuration
########################################

[tmc2209 stepper_x]
uart_pin: PC13
run_current: 0.850
hold_current: 0.500
diag_pin: PF4
#driver_SGTHRS: 120
interpolate: True

[tmc2209 stepper_y]
uart_pin: PE3
run_current: 0.850
diag_pin: PF3
#driver_SGTHRS: 110
interpolate: True

[tmc2209 stepper_z]
uart_pin: PB9
run_current: 0.750
hold_current: 0.500
#diag_pin: PF2
interpolate: True
stealthchop_threshold: 999999

[tmc2209 stepper_z1]
uart_pin: PB5
run_current: 0.750
hold_current: 0.500
#diag_pin: PF1
interpolate: True
stealthchop_threshold: 999999

[tmc2209 extruder]
uart_pin: PG14
run_current: 0.900
hold_current: 0.300
#diag_pin: PC2
interpolate: True

#[tmc2209 extruder1]
#uart_pin: PA6
#run_current: 0.600
#diag_pin:

[autotune_tmc stepper_x]
motor: creality-42-40
#tuning_goal: silent
tuning_goal: performance
#extra_hysteresis: 4
sg4_thrs: 120

[autotune_tmc stepper_y]
motor: creality-42-40
#tuning_goal: silent
tuning_goal: performance
#extra_hysteresis: 4
sg4_thrs: 130

[autotune_tmc stepper_z]
motor: moons-c17hd2024n-01n
tuning_goal: silent
#tuning_goal: performance
[autotune_tmc stepper_z1]
motor: moons-c17hd2024n-01n
tuning_goal: silent
#tuning_goal: performance
[autotune_tmc extruder]
motor: biqu-35BYGF0713-A-10HZT
#tuning_goal: silent
tuning_goal: performance


########################################
# TMC2130 configuration
########################################

#[tmc2130 stepper_x]
#cs_pin: PD9
#spi_bus: spi2
#run_current: 0.800
#stealthchop_threshold: 999999
#diag1_pin: PD3

#[tmc2130 stepper_y]
#cs_pin: PD8
#spi_bus: spi2
#run_current: 0.800
#stealthchop_threshold: 999999
#diag1_pin: PD2

#[tmc2130 stepper_z]
#cs_pin: PB10
#spi_bus: spi2
#run_current: 0.650
#stealthchop_threshold: 999999
#diag1_pin: PC3

#[tmc2130 extruder]
#cs_pin: PB2
#spi_bus: spi2
#run_current: 0.800
#stealthchop_threshold: 999999
#diag1_pin: PC2

#[tmc2130 extruder1]
#cs_pin: PA6
#spi_bus: spi2
#run_current: 0.800
#stealthchop_threshold: 999999
#diag1_pin:

#[board_pins]
#aliases:
    # EXP1 header
 #   EXP1_1=PD5, EXP1_3=PB3, EXP1_5=PB5, EXP1_7=PB7, EXP1_9=<GND>,
 #   EXP1_2=PD4,  EXP1_4=PD6, EXP1_6=PB4, EXP1_8=PB6, EXP1_10=<5V>,
    # EXP2 header
 #   EXP2_1=PB14, EXP2_3=PB8, EXP2_5=PC10, EXP2_7=PC12,  EXP2_9=<GND>,
 #   EXP2_2=PB13, EXP2_4=PB9, EXP2_6=PB15, EXP2_8=<RST>, EXP2_10=<NC>

#[display]
#lcd_type: st7920
#cs_pin: EXP1_7
#sclk_pin: EXP1_6
#sid_pin: EXP1_8
#encoder_pins: ^EXP1_5, ^EXP1_3
#click_pin: ^!EXP1_2

#[output_pin beeper]
#pin: EXP1_1

#[display]
#lcd_type: uc1701
#cs_pin: EXP1_3
#a0_pin: EXP1_4
#rst_pin: EXP1_5
#contrast: 63
#encoder_pins: ^EXP2_5, ^EXP2_3
#click_pin: ^!EXP1_2

# See the sample-lcd.cfg file for definitions of common LCD displays.

#[bltouch]
#sensor_pin: PC13
#control_pin: PC15

# Proximity switch
#[probe]
#pin: PC15

#[neopixel my_neopixel1]
#pin: PC11

#[neopixel my_neopixel2]
#pin: PC14

#[adxl345]
#cs_pin: PC0
#spi_bus: spi2


[idle_timeout]
gcode:
  {% if printer.pause_resume.is_paused %}

    M118 Idle timeout while paused, turning off hotend

    SET_HEATER_TEMPERATURE HEATER=extruder TARGET=0

  {% else %}

    M118 Idle timeout

    TURN_OFF_HEATERS

    M84

  {% endif %}

timeout: 1200


#*# <---------------------- SAVE_CONFIG ---------------------->
#*# DO NOT EDIT THIS BLOCK OR BELOW. The contents are auto-generated.
#*#
#*# [bed_mesh default]
#*# version = 1
#*# points =
#*# 	0.388961, 0.361773, 0.203336, 0.095836, -0.106039
#*# 	0.417398, 0.360523, 0.203023, 0.087086, -0.099164
#*# 	0.384273, 0.296773, 0.176148, 0.020523, -0.122289
#*# 	0.500523, 0.423648, 0.289273, 0.160836, 0.012086
#*# 	0.521148, 0.452711, 0.331148, 0.213336, 0.031773
#*# x_count = 5
#*# y_count = 5
#*# mesh_x_pps = 2
#*# mesh_y_pps = 2
#*# algo = lagrange
#*# tension = 0.15
#*# min_x = 20.0
#*# max_x = 195.0
#*# min_y = 20.0
#*# max_y = 210.0
#*#

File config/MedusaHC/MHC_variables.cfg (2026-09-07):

[save_variables]
filename: ~/printer_data/config/saved_vars.cfg

[gcode_macro _TOOL_CFG]
# Rack orientation: 1 for front docks, -1 for rear docks.
variable_tools_direction: 1

# X coordinate of the T0 dock center.
variable_x_t0: 17
# X coordinate of the T1 dock center.
variable_x_t1: 82
# X coordinate of the T2 dock center.
variable_x_t2: 147
# X coordinate of the T3 dock center.
variable_x_t3: 212
# Safe Y coordinate used before entering or after leaving a dock.
variable_y_safe: -5
# Y coordinate where a tool engages the dock latch.
variable_y_latch: -57.6
# X movement used to engage or release the dock latch.
variable_x_shift: 9

# Acceleration used during tool-change travel moves.
variable_fast_accel: 10000
# Fast travel speed between safe and dock positions.
variable_fast_speed: 300
# Slow speed used while engaging or releasing a dock.
variable_slow_speed: 40

# Y coordinate of the nozzle priming path.
variable_y_prime: -45.0
# Y coordinate of the nozzle brush.
variable_y_brush: -45.0
# X distance from the dock center to the priming and cleaning path.
variable_x_prime_shift: 12

# Motor rotation distance that opens the feeder and releases the filament.
variable_e_open: -5
# Motor rotation distance that closes the feeder and grips the filament.
variable_e_close: 3

# Servo angle that presses the upper auxiliary gear against the motor for opening.
variable_servo_open_angle: 90
# Servo angle that moves the upper auxiliary gear away for the closed position.
variable_servo_close_angle: 180

# Temporary extruder-current multiplier used while opening the feeder.
# Cached at initialization: restart Klipper after changing this value or run_current.
variable_e_cur_high_mult: 1.7

gcode:

[gcode_macro _GLOBAL_STATE]
# Number of installed tools.
variable_max_tool: 4

# Additional Z offset applied after tap.
variable_eddy_z: 0.0

#------------- Do not change ---------------

# Current print layer reported by the slicer integration.
variable_layer: 0

# X/Y motor currents are not currently used and remain commented for future use.
# Only the extruder current (e_cur / e_cur_high) is active; it is boosted
# during feeder OPEN to avoid skipped steps on the latch.
#variable_x_cur: 0.0
#variable_x_cur_high: 0.0      # x_cur * mult
#variable_y_cur: 0.0
#variable_y_cur_high: 0.0      # y_cur * mult
# Extruder run current detected during initialization.
variable_e_cur: 0.0
# Boosted extruder current used to operate the feeder latch.
variable_e_cur_high: 0.0

# Tool requested by the current tool-change operation.
variable_target_tool: -1
# Last internal MedusaHC error state.
variable_error_state: 0
# Stored T0 probe Z reference used during calibration.
variable_t0_probe_z: 0.0

# Feeder latch state: 0 closed, 1 open.
variable_feeder_open: 0

# Cached fast travel feed rate in mm/min.
variable_fast_feedrate: 0.0
# Cached slow docking feed rate in mm/min.
variable_slow_feedrate: 0.0

#variable_prime_flag: 0

gcode:

[gcode_macro _TOOL_STATE_0]
# Filament extruded during the normal prime for this tool.
variable_prime_amount: 13
# Extrusion speed used for the normal prime.
variable_prime_speed: 30
# Retraction performed after the normal prime.
variable_prime_retract: 0.7
# Retraction speed used after the normal prime.
variable_prime_retract_speed: 40

# Enables or disables the cleaning movement for this tool.
variable_clean_move: 1
# X amplitude of the cleaning movement.
variable_x_clean_move: 8
# Y amplitude of the cleaning movement.
variable_y_clean_move: 5
# Brush crossing speed for this tool, in mm/s.
variable_clean_move_speed: 250
# Slow extrusion speed used while cleaning the PTFE path.
variable_ptfe_clean_slow_speed: 12.5
# Retraction performed after cleaning.
variable_clean_retract: 0.8
# Retraction speed used after cleaning.
variable_clean_retract_speed: 35

# Enables first-use priming for this tool. The runtime flag below is managed automatically.
variable_first_prime_enabled: 1
variable_first_prime_flag: 1  # Internal state: 0 = pending, 1 = already completed.
# Extra filament extruded on the first use of this tool.
variable_first_prime_amount: 5
# Extrusion speed used for the first prime.
variable_first_prime_speed: 6
# Retraction performed immediately after the first prime.
variable_first_prime_prime_retract: 0.2
# Retraction performed after first-prime cleaning.
variable_first_prime_clean_retract: 0.1
gcode:


[gcode_macro _TOOL_STATE_1]
# Filament extruded during the normal prime for this tool.
variable_prime_amount: 13
# Extrusion speed used for the normal prime.
variable_prime_speed: 30
# Retraction performed after the normal prime.
variable_prime_retract: 0.7
# Retraction speed used after the normal prime.
variable_prime_retract_speed: 40

# Enables or disables the cleaning movement for this tool.
variable_clean_move: 1
# X amplitude of the cleaning movement.
variable_x_clean_move: 8
# Y amplitude of the cleaning movement.
variable_y_clean_move: 5
# Brush crossing speed for this tool, in mm/s.
variable_clean_move_speed: 250
# Slow extrusion speed used while cleaning the PTFE path.
variable_ptfe_clean_slow_speed: 12.5
# Retraction performed after cleaning.
variable_clean_retract: 0.9
# Retraction speed used after cleaning.
variable_clean_retract_speed: 35

# Enables first-use priming for this tool. The runtime flag below is managed automatically.
variable_first_prime_enabled: 1
variable_first_prime_flag: 1  # Internal state: 0 = pending, 1 = already completed.
# Extra filament extruded on the first use of this tool.
variable_first_prime_amount: 5
# Extrusion speed used for the first prime.
variable_first_prime_speed: 6
# Retraction performed immediately after the first prime.
variable_first_prime_prime_retract: 0.2
# Retraction performed after first-prime cleaning.
variable_first_prime_clean_retract: 0.1
gcode:


[gcode_macro _TOOL_STATE_2]
# Filament extruded during the normal prime for this tool.
variable_prime_amount: 13
# Extrusion speed used for the normal prime.
variable_prime_speed: 30
# Retraction performed after the normal prime.
variable_prime_retract: 0.7
# Retraction speed used after the normal prime.
variable_prime_retract_speed: 40

# Enables or disables the cleaning movement for this tool.
variable_clean_move: 1
# X amplitude of the cleaning movement.
variable_x_clean_move: 8
# Y amplitude of the cleaning movement.
variable_y_clean_move: 5
# Brush crossing speed for this tool, in mm/s.
variable_clean_move_speed: 250
# Slow extrusion speed used while cleaning the PTFE path.
variable_ptfe_clean_slow_speed: 12.5
# Retraction performed after cleaning.
variable_clean_retract: 0.9
# Retraction speed used after cleaning.
variable_clean_retract_speed: 35

# Enables first-use priming for this tool. The runtime flag below is managed automatically.
variable_first_prime_enabled: 1
variable_first_prime_flag: 1  # Internal state: 0 = pending, 1 = already completed.
# Extra filament extruded on the first use of this tool.
variable_first_prime_amount: 5
# Extrusion speed used for the first prime.
variable_first_prime_speed: 6
# Retraction performed immediately after the first prime.
variable_first_prime_prime_retract: 0.2
# Retraction performed after first-prime cleaning.
variable_first_prime_clean_retract: 0.1
gcode:


[gcode_macro _TOOL_STATE_3]
# Filament extruded during the normal prime for this tool.
variable_prime_amount: 13
# Extrusion speed used for the normal prime.
variable_prime_speed: 30
# Retraction performed after the normal prime.
variable_prime_retract: 0.7
# Retraction speed used after the normal prime.
variable_prime_retract_speed: 40

# Enables or disables the cleaning movement for this tool.
variable_clean_move: 1
# X amplitude of the cleaning movement.
variable_x_clean_move: 8
# Y amplitude of the cleaning movement.
variable_y_clean_move: 5
# Brush crossing speed for this tool, in mm/s.
variable_clean_move_speed: 250
# Slow extrusion speed used while cleaning the PTFE path.
variable_ptfe_clean_slow_speed: 12.5
# Retraction performed after cleaning.
variable_clean_retract: 0.9
# Retraction speed used after cleaning.
variable_clean_retract_speed: 35

# Enables first-use priming for this tool. The runtime flag below is managed automatically.
variable_first_prime_enabled: 1
variable_first_prime_flag: 1  # Internal state: 0 = pending, 1 = already completed.
# Extra filament extruded on the first use of this tool.
variable_first_prime_amount: 5
# Extrusion speed used for the first prime.
variable_first_prime_speed: 6
# Retraction performed immediately after the first prime.
variable_first_prime_prime_retract: 0.2
# Retraction performed after first-prime cleaning.
variable_first_prime_clean_retract: 0.1
gcode:

[gcode_macro _TOOL_OFFSET]
description: Store per-tool gcode offsets

# Z offset applied when T0 is active.
variable_t0_off_z: 0.0
# X offset applied when T0 is active.
variable_t0_off_x: 0.0
# Y offset applied when T0 is active.
variable_t0_off_y: 0.0
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

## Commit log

2026-04-01 Update MHC_macros.cfg
    Individual cleaning and priming settings were added for each hotend. This is needed when printing with different filaments or materials with different properties. First-use priming was also added whe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
    [MHC_macros.cfg]
2026-04-01 Update MHC_variables.cfg
    The individual priming and cleaning settings for each hotend are stored in the macros TOOL_STATE_0, TOOL_STATE_1, and so on. Each hotend in the system must have its own macro like this.
    [MHC_variables.cfg]
2026-05-14 Update calibrate-offsets.cfg
    Made tool calibration easier to configure.
    - CALIBRATE_MOVE_OVER_PROBE: the approximate position above the tool calibration probe is no longer hardcoded inside the g-code. The X, Y and Z coordinates are now stored as variables (variable_probe_x, variable_probe_y, variable_probe_z) on the same macro, so the probe location can be adjusted in one obvious place without editing the move commands.
    - CALIBRATE_TOOL_OFFSETS and CALIBRATE_AND_SAVE_OFFSETS: removed the hardcoded tool list [1, 2, 3]. The loop now uses range(1, max_tool), reading max_tool from GLOBAL_STATE. T0 is still calibrated separately as the reference tool before the loop. Adding or removing a tool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
    [calibrate-offsets.cfg]
2026-05-14 Update MHC_variables.cfg
    Exposed feeder-related tuning parameters and cleaned up unused state.
    - TOOL_CFG: added variable_e_open (default -4) and variable_e_close (default 0.5). These define how far and in which direction the extruder motor turns to open and close the feeder latch. The sign sets direction (open is negative, close is positive by default); flipping the sign inverts the motion if the extruder is wired or mounted the other way around.
    - TOOL_CFG: added variable_e_cur_high_mult (default 1.6). This is the multiplier applied to the extruder's base TMC run_current to get the boosted current used while opening the feeder latch. The boost is needed so the motor has enough torque t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
    [MHC_variables.cfg]
2026-05-14 Update MHC_macros.cfg
    Reworked feeder-related macros to use the new TOOL_CFG variables and removed dead code.
    - CLOSE: the hardcoded extruder move G1 E0.5 is replaced with G1 E{e_close}, with the value taken from TOOL_CFG. The feeder closing distance can now be tuned without touching the macro.
    - OPEN_MOVE: the hardcoded opening move G1 E-4 is replaced with G1 E{e_open}, also taken from TOOL_CFG. The short wiggle sequence (E±0.2 pulses) at the start of OPEN_MOVE is left as is — it's a mechanical step that helps the extruder gears engage with the latch and is not user-tunable.
    - INIT_SENSOR_STATE: removed the X/Y current pipeline. Previously the macro read tmc_x and tmc_y run_current,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
    [MHC_macros.cfg]
2026-05-14 Update README.md
    README: document recent configuration changes
    - Document new TOOL_CFG variables: e_open, e_close, e_cur_high_mult
    - Document configurable probe position variables in CALIBRATE_MOVE_OVER_PROBE
    - Document that tool calibration loops are now bound to max_tool
    - Update INIT_SENSOR_STATE description to reflect removal of X/Y current handling
2026-05-18 Update MHC_config.cfg
    All T{X} macros in MHC_config gain variable_active and variable_color,
    which are required by Mainsail to render the tools panel.
    [MHC_config.cfg]
2026-05-18 Update calibrate-offsets.cfg
    calibrate-offsets: pull last_result from tools_calibrate instead of APPLY=1
    Replace TOOL_CALIBRATE_TOOL_OFFSET APPLY=1 with a vanilla call followed
    by _APPLY_LAST_RESULT_TO_TOOL_OFFSET, which reads
    printer.tools_calibrate.last_x_result/last_y_result/last_z_result and
    writes both TOOL_OFFSET (runtime) and saved_vars in one step.
    The local fork of tools_calibrate.py is no longer needed; the stock
    script from klipper-toolchanger works as-is and can be updated freely.
    [calibrate-offsets.cfg]
2026-05-18 Update pin_watch.py
    pin_watch: add Mainsail UI sync for active tool and endstop indicators
    Two independent toggles in [pin_watch io]:
    - sync_mainsail_tools highlights the currently active T<N> button
    via variable_active, updated when a tool is successfully picked up.
    - sync_mainsail_sensors sets variable_color to mirror endstop state:
    green when pressed (tool parked in dock), red when released
    (tool missing). The active tool's lamp is forced blue regardless
    of its own endstop, so the operator can see at a glance which tool
    is in use and spot anomalies if something goes wrong.
    Each sync call is isolated in its own try/except so a failure in
    toolchanger sync (e.g. axis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
2026-05-18 Update MHC_macros.cfg
    Rename DROP_CLOSE macro to DROP_TOOL for clarity (avoids confusion with the internal DROP macro)
    [MHC_macros.cfg]
2026-05-18 Update macros.cfg
    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
    [macros.cfg]
2026-05-18 Update eddy_ng.cfg
    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
    [eddy_ng.cfg]
2026-05-18 Update eddy_ng_features.cfg
    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
    [eddy_ng_features.cfg]
2026-05-18 Update pin_watch.py
    of its own endstop, so the operator can see at a glance which
    tool is in use and spot anomalies if something goes wrong.
    Lamp updates fire directly from pin edge callbacks for instant
    response. Each sync call i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
2026-06-12 Update README.md
    Сlarify license terms in README
2026-08-04 Release MedusaHC V0.2 beta
    Add V-Front and V-Back layouts with updated printable parts and a full STEP reference assembly.
    Update the four-tool Duender configuration, direction-aware tool handling, native Klipper Eddy tap support, klipper-toolchanger calibration, slicer projects, scripts, and documentation.
    Remove obsolete V0.1, Eddy-ng, duplicate, and unused files while retaining the manual, BOM references, license, and SexBall mounting parts.
    [4Rca cube.3mf, 4rcaCube.3mf, 4rcaCube_orca_project.3mf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]
2026-08-04 Preserve original STEP file
    Re-add the V0.2 STEP assembly as a binary file so Git stores the exact original bytes without line-ending normalization.
2026-08-04 Add detailed V0.2 release notes
    Document the V0.2 mechanical layouts, configuration changes, calibration workflow, slicer updates, repository reorganization, compatibility notes, and removed legacy files.
2026-08-04 Restore Duender front mount adapters
    Restore the original left and right glue-on profile adapters from the V0.1 history, place them with the V-Front mounts, and correct the installation documentation and changelog.
    [Base_Profile_Mount_L.stl, Base_Profile_Mount_R.stl]
2026-08-12 Update sensorless.cfg
    Add small extruder movement to wake up the motor for tool change operations.
    [sensorless.cfg]
2026-08-24 Redesign feeder servo opening linkage
    Replace the eccentric opener with a dual-lever linkage using two 693-2RS bearings for smoother, more positive operation. Reposition the servo below the feeder profile to reduce its influence on resonances.
    Update the printable feeder set and add the STEP assembly. Document the modified stock servo horn, reversed servo direction and angle setup, and recommend reprinting the full set even though some parts only received minor rounding changes.
    [Feeder Body 1.stl, Feeder Body 2.stl, Feeder Lever 2 Cover.stl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]
2026-08-24 Update feeder STEP assembly
    Replace the feeder linkage STEP assembly with the latest revised model.
    [MedusaHC_Feeder_Lever_MOD.step]
2026-08-24 Document experimental feeder STEP assembly
    Move the revised feeder assembly next to the main MedusaHC STEP file and clarify that it represents a separate experimental feeder. If testing is successful, this design will become the main feeder a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
    [MedusaHC_Feeder_Lever_MOD.step]
2026-08-24 Clarify feeder STL version availability
    Note that the standalone feeder STLs already contain the experimental design, while the previous feeder remains available in the full MedusaHC V0.2 STEP assembly.
2026-08-24 Align macro servo defaults with Python controller
    [MHC_config.cfg, MHC_macros.cfg, MHC_variables.cfg]
2026-08-24 Separate first-prime enable state and honor clean toggle
    [MHC_macros.cfg, MHC_variables.cfg]
2026-08-24 Document MedusaHC configuration variables
    [MHC_variables.cfg]
2026-08-30 Make Python controller the default
    [4rcaCube.3mf, 4rcaCube_orca_project.3mf, Line_Purge.cfg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]
2026-08-31 Fix Core config include layout
    [MHC_variables.cfg]
2026-08-31 Keep Core includes in source config
    [MHC_config.cfg]
2026-09-01 Align repository with installed Core layout
    [Line_Purge_examples.cfg, MHC_config.cfg, MHC_macros.cfg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]
2026-09-07 Fix prime positioning, brush speed and Core reinstall
    Move to Y_prime before extrusion and anchor brush crossings to Y_brush at clean_speed. Preserve mirrored dock geometry and the existing current initialization behavior. Restore Core over retained configuration without overwriting live settings, and avoid treating retained panel configuration as an installed dependency.
    Document required homing helper, saved-offset precedence and restart requirements. Validation: 2 regression tests covering mirrored motion and the install/update/uninstall/reinstall cycle; shell syntax checked. Physical printer motion was not tested.
    [MHC_variables.cfg]
2026-09-07 Use per-tool clean_move_speed for all brush crossings
    Read clean_move_speed from the selected TOOL_STATE profile for standalone CLEAN and post-pick cleaning. Remove the unused shared clean_speed and clean_feedrate from initialization, motion values and 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
    Validation: 3 tests passed, including different speeds for two tools, runtime changes, both cleaning entrypoints, mirrored geometry and configuration-preserving reinstall.
    [MHC_variables.cfg]
2026-09-08 Move to y_brush before starting any cleaning strokes
    Finish priming and the prime retract at y_prime with x_prime_shift, then move directly in Y to y_brush before cleaning X movement. Anchor the entire existing PTFE and brush path to y_brush in post-pi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
    Validation: both motion tests passed, covering distinct prime and brush positions, front/rear docks, per-tool speeds, first slow stroke location, immediate Y travel after prime retract, and cleaning 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
2026-09-13 Preserve print state during MedusaHC pause recovery
    Record sensor_error only for failed SET/DROP operations and avoid a second park when recovery fails again while paused. Add MHC_RESUME to prepare the target tool, prime and clean it during recovery, preserve the saved layer and E state, and let the slicer's next move take the new tool to the print position.
    Update the stock PAUSE/RESUME example for the standard Duender Y220/X0 parking geometry. Document the required manual migration for custom printer macros; the Core updater preserves live configs and does not restart Klipper. Verify slicer G-code sets Z before extrusion after a tool change.
    Validation: 20 Core unit and installer tests p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
    [MHC_config.cfg, macros_examples.cfg]
2026-09-14 Remove duplicate unprefixed G-code commands
    Register only the MHC_* controller commands. Remove DROP, TOOL_OFFSET_T, LAYER_SET and PRIME_FLAGS_SET aliases and the unused Python prime-flags handler so existing user macros can own those names without preventing Klipper startup.
    Document the replacement command names and the matching MedusaHC Control update. Verify registration alongside existing user macro names; Core, Control and Calibrate test suites pass.
2026-09-18 Add G-code offsets for multiple tool heads
    Saved offsets example
    [saved_vars.cfg]
2026-10-03 Stop part cooling fan when tool changes fail
    Turn off the part cooling fan before MHC_ERROR pauses a print and in the final cleanup of SET and DROP operations, including unexpected exceptions. Preserve existing fan activation during docking.
    Add regression coverage for successful operations, unexpected motion errors, and error handling with active or inactive prints. All 22 controller tests pass.
2026-10-03 Remove regression tests added with fan cleanup fix
2026-10-03 Remove local development tests from public repository
    Keep internal installer, motion, pause recovery, and sensor error checks local. Runtime controller and installer behavior are unchanged.
